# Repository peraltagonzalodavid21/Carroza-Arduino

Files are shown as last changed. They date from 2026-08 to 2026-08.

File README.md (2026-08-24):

## Bienvenida:
Buenasss, no se quien este leyendo esto, pero mientras voy comentando como esta planteado esto, en este repositorio se encuentra todo el codigo de la carroza, un poco de los diagramas para usar de referencia, ademas de intrucciones para poner a punto la placa y algunos consejos que pueden ser utiles al momento de armarla. Ademas del MIT app inventor para programar la app. Tambien voy a dejar las capturas y el archivo de kicad para futuras mejoras que voy a comentar al final.

## Creditos:

Aca aunque ya me conozcan dejo mi nombre y promo por si este repo se sigue utilizando:

Alumno: Peralta Gonzalo David
Promo: 2025
Colegio: E.P.E.T N°12
Año: 2026

## Hardware del Proyecto

El sistema de control funciona con los siguientes componentes:
* Microcontrolador: Arduino Nano (se utilizan todos los pines digitales del D2 al D13, 12 salidas en total).
* Módulo Bluetooth: HC-05 (para la conexión con la aplicación).
* Drivers de Potencia: ULN2003 para el manejo seguro de los relés.
* Actuadores: 12 Relés de 5V (4 para movimiento, 8 para accesorios/luces).
* Alimentación: Módulo Step-down LM2596 (Regula de 12V a 5V para alimentar la lógica).

## Diagrama de Pines (Pinout) y Mapeo Bluetooth

Es fundamental conectar los pines correctamente según la siguiente tabla:

| Relé / Función | Pin en Arduino | Tipo de Botón en App | Letra ON | Letra OFF |
|---|---|---|---|---|
| Relé 1 (Adelante) | D2 | Momentáneo | A | a |
| Relé 2 (Atrás) | D3 | Momentáneo | B | b |
| Relé 3 (Izquierda)| D4 | Momentáneo | C | c |
| Relé 4 (Derecha) | D5 | Momentáneo | D | d |
| Relé 5 (Mas)| D6 | Momentáneo | E | e |
| Relé 6 (Menos)| D7 | Momentáneo | F | f |
| Relé 7 (Accesorio 1)| D8 | Toggle (Interruptor) | G | g |
| Relé 8 (Accesorio 2)| D9 | Toggle (Interruptor) | H | h |
| Relé 9 (Accesorio 3)| D10 | Toggle (Interruptor) | I | i |
| Relé 10 (Accesorio 4)| D11 | Toggle (Interruptor) | J | j |
| Relé 11 (Accesorio 5)| D12 | Toggle (Interruptor) | K | k |
| Relé 12 (Accesorio 6)| D13 | Toggle (Interruptor) | L | l |
| EMERGENCIA (STOP) | N/A | Botón de Pánico | X | N/A |

Nota sobre el funcionamiento de los botones:
- Momentáneo: La acción se ejecuta solo mientras se mantiene presionado el botón en la aplicación.
- Toggle: Funciona como un interruptor estándar. Se presiona una vez para encender y otra para apagar.

## Guía de Instalación (5 Pasos)

Para poner en marcha el control de la carroza, seguir estos pasos:

1. Paso 1 - Cargar el código:
   Descargar el código Arduino desde este repositorio, abrirlo en el IDE y cargarlo al Arduino Nano (asegurarse de configurar el puerto y el tipo de placa correctos).
2. Paso 2 - Conectar los módulos:
   Conectar el módulo HC-05 (TX a RX y RX a TX del Arduino), el regulador LM2596 (ajustado a 5V) y el ULN2003 a los pines de los relés según la tabla anterior.
3. Paso 3 - Descargar la app:
   Descargar la aplicación desde el repositorio (archivo .aia) o importarla desde el enlace compartido de MIT App Inventor.
4. Paso 4 - Instalar y vincular:
   Instalar la aplicación en el dispositivo Android y vincular el módulo HC-05 mediante Bluetooth desde los ajustes del sistema.
5. Paso 5 - Probar la seguridad:
   Abrir la aplicación, conectar el Bluetooth y probar inmediatamente el botón de STOP (EMERGENCIA) para verificar que todos los relés se apagan correctamente.

## Cómo agregar un nuevo relé en 1 minuto

Si en el futuro es necesario agregar más funcionalidades, el procedimiento es el siguiente:

1. Ir al código Arduino, copiar una función rele13_ON() y su correspondiente OFF, pegarla y cambiarle el número.
2. Agregar un nuevo else if en la sección del loop() para capturar la nueva letra (por ejemplo, 'M' y 'm').
3. Actualizar el array de pines al inicio del código, si corresponde.
4. En la aplicación (MIT App Inventor), copiar un interruptor (switch) existente, cambiarle el nombre y configurarlo para que envíe las nuevas letras ('M' y 'm').

## Carpetas del repo
/Codigo_Arduino → Archivo .ino con el programa principal.

/App_MIT_Inventor → Archivo .aia de la app, Si se abre el mit app inventor pueden modificar la app.

/PCB_KiCad → Archivos del esquemático y diseño de la PCB, Si se abre el KiCad pueden modificar la PCB.

/Docs → Imágenes, diagramas, fotos de la carroza, etc. Aca tambien ya dejo un par de capturas de la carroza.

## Galería

Se recomienda agregar fotos de la PCB, los circuitos, el chasis y la carroza terminada en la carpeta /Docs como registro visual del trabajo. (Creen una carpeta con el año y fotos de la carroza, placa, etc). 

## Cierre
Bueno aca ya dejo el cierre, no se quien lea esto pero espero que el proyecto siga avanzando y mejoren, como un esp32 con mas pines y bluetooth integrado, ya que es el proximo paso, o que la carroza no se mueva sola pero tenga un show de luces o algo mas elaborado, como un sistema que se prenda solo cuando tenga musica fuerte, no se, depende de la creatividad de cada uno. 

Mientras tanto los dejo tranquilos, yo voy a ver si la facu no me mata, saludos.

-Peralta Gonzalo David.

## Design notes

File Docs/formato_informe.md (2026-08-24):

# INFORME TÉCNICO – CONTROL DE CARROZA ESTUDIANTINA

**Versión:** [AÑO]  
**Autor:**  
**Institución:** E.P.E.T N°12
**Fecha de emisión:** [Fecha de entrega del informe]  

---

## 1. OBJETIVO DEL PROYECTO

Desarrollar un sistema de control inalámbrico para la carroza de la Semana de la Estudiantina, que permita manejar los motores de desplazamiento y los accesorios (luces, bocinas, etc.) desde un dispositivo Android, reemplazando los engorrosos sistemas de cableado tradicionales y brindando seguridad y facilidad de operación a los estudiantes.

---

## 2. DESCRIPCIÓN DEL SISTEMA

### 2.1. Hardware utilizado
- **Microcontrolador:** Arduino Nano (ATmega328P).
- **Módulo Bluetooth:** HC-05 (esclavo).
- **Driver de relés:** [Especificar según año, ej: Transistores + optoacopladores / ULN2003].
- **Relés:** [Especificar voltaje y cantidad, ej: 12 relés de 12V].
- **Fuente de alimentación:** [Especificar, ej: LM2596 step-down (12V a 5V)].
- **PCB:** [Especificar, ej: Placa perforada / PCB personalizada con planchado].

### 2.2. Software utilizado
- **IDE de programación:** Arduino IDE (versión [indicar]).
- **Entorno de desarrollo de la app:** MIT App Inventor 2.
- **Diseño de PCB:** KiCad (versión [indicar]).
- **Lenguajes:** C++ (Arduino) / Bloques visuales (MIT App Inventor).

---

## 3. CRONOGRAMA Y HITOS

| Fecha | Hito / Actividad |
| :--- | :--- |
| [DD/MM] | [Descripción de la actividad, ej: Inicio del desarrollo del código] |
| [DD/MM] | [Descripción, ej: Primeras pruebas en protoboard] |
| [DD/MM] | [Descripción, ej: Fabricación de la PCB] |
| [DD/MM] | [Descripción, ej: Armado final y pruebas en carroza] |

*(Completar con las fechas reales del año correspondiente)*

---

## 4. MEJORAS Y CAMBIOS RESPECTO AL AÑO ANTERIOR

*(Si es la primera versión, aclarar que es el prototipo inicial)*

- [Mejora 1, ej: Se eliminaron los optoacopladores y se utilizó un ULN2003 para simplificar el circuito].
- [Mejora 2, ej: Se diseñó una PCB con método de planchado, reemplazando la placa perforada].
- [Mejora 3, ej: Se añadieron borneras para facilitar el cableado en la carroza].

---

## 5. INCIDENCIAS Y SOLUCIONES APLICADAS

| Problema encontrado | Solución implementada |
| :--- | :--- |
| [Ej: Se quemó un ULN2003 por inversión de polaridad] | [Ej: Se reemplazó el integrado y se agregó un diodo de protección en el esquemático] |
| [Ej: Contacto de bornera flojo en la carroza] | [Ej: Se ajustaron los tornillos y se verificó el apriete de todas las conexiones] |

---

## 6. CONCLUSIONES Y SUGERENCIAS PARA PRÓXIMAS VERSIONES

- **Conclusión general:** El sistema funcionó correctamente durante el evento, cumpliendo con los requisitos de manejo y seguridad.
- **Sugerencia 1:** Agregar un botón físico de emergencia en el tablero (independiente de la app).
- **Sugerencia 2:** Considerar reemplazar el HC-05 por un módulo BLE (HM-10) para compatibilidad con iOS.
- **Sugerencia 3:** Diseñar una carcasa protectora (impresión 3D) para la PCB.
- **Sugerencia 4:** Ampliar el número de relés si se agregan más accesorios (actualmente 12, se puede extender usando un multiplexor o cambiando de microcontrolador).

---

## 7. ANEXOS

- Código fuente (Arduino): disponible en `/Codigo_Arduino` del repositorio.
- App (MIT App Inventor): disponible en `/App_MIT_Inventor` y enlace de proyecto compartido.
- Esquemático y PCB (KiCad): disponibles en `/PCB_KiCad`.
- Fotos y diagramas: disponibles en `/Docs/imagenes`.

---

**Nota:** Este informe es un registro histórico del proyecto. Está sujeto a modificaciones y actualizaciones según los requerimientos de cada año, los avances tecnológicos y las lecciones aprendidas durante la puesta en marcha.

---
*“La técnica es el puente entre la idea y la realidad.”*

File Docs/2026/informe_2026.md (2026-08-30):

# INFORME TÉCNICO – CONTROL DE CARROZA ESTUDIANTINA

**Versión:** [2026]  
**Autor:** Adriel Nicolás Balbuena 
**Institución:** E.P.E.T N°12
**Fecha de emisión:** [24/08/26]  

---

## 1. OBJETIVO DEL PROYECTO

Desarrollar un sistema de control inalámbrico para la carroza de la Semana de la Estudiantina, que permita manejar los motores de desplazamiento y los accesorios (luces, bocinas, etc.) desde un dispositivo Android, reemplazando los engorrosos sistemas de cableado tradicionales y brindando seguridad y facilidad de operación a los estudiantes.

---

## 2. DESCRIPCIÓN DEL SISTEMA

### 2.1. Hardware utilizado
- **Microcontrolador:** Arduino Nano (ATmega328P).
- **Módulo Bluetooth:** HC-05 (esclavo).
- **Driver de relés:** [Especificar según año, ej: Transistores + optoacopladores / ULN2003].
- **Relés:** [Especificar voltaje y cantidad, ej: 12 relés de 12V].
- **Fuente de alimentación:** [Especificar, ej: LM2596 step-down (12V a 5V)].
- **PCB:** [Especificar, ej: Placa perforada / PCB personalizada con planchado].

### 2.2. Software utilizado
- **IDE de programación:** Arduino IDE (versión [indicar]).
- **Entorno de desarrollo de la app:** MIT App Inventor 2.
- **Diseño de PCB:** KiCad (versión [indicar]).
- **Lenguajes:** C++ (Arduino) / Bloques visuales (MIT App Inventor).

---

## 3. CRONOGRAMA E HITOS

| Fecha | Hito / Actividad |
| :--- | :--- |
| [DD/MM] | [Descripción de la actividad, ej: Inicio del desarrollo del código] |
| [DD/MM] | [Descripción, ej: Primeras pruebas en protoboard] |
| [DD/MM] | [Descripción, ej: Fabricación de la PCB] |
| [DD/MM] | [Descripción, ej: Armado final y pruebas en carroza] |
| 26/08 | Desoldado del HC-05 para pruebas con el Arduino Nano. |
| 26/08 | Preparación de planchas para la colocación de los finales de carrera. |
| 28/08 | Colocación de los finales de carrera. |
*(Completar con las fechas reales del año correspondiente)*

---

## 4. MEJORAS Y CAMBIOS RESPECTO AL AÑO ANTERIOR

*(Si es la primera versión, aclarar que es el prototipo inicial)*

- [Mejora 1, ej: Se eliminaron los optoacopladores y se utilizó un ULN2003 para simplificar el circuito].
- [Mejora 2, ej: Se diseñó una PCB con método de planchado, reemplazando la placa perforada].
- [Mejora 3, ej: Se añadieron borneras para facilitar el cableado en la carroza].

---

## 5. INCIDENCIAS Y SOLUCIONES APLICADAS

| Problema encontrado | Solución implementada |
| :--- | :--- |
| [Ej: Se quemó un ULN2003 por inversión de polaridad] | [Ej: Se reemplazó el integrado y se agregó un diodo de protección en el esquemático] |
| [Ej: Contacto de bornera flojo en la carroza] | [Ej: Se ajustaron los tornillos y se verificó el apriete de todas las conexiones] |

---

## 6. CONCLUSIONES Y SUGERENCIAS PARA PRÓXIMAS VERSIONES

- **Conclusión general:** El sistema funcionó correctamente durante el evento, cumpliendo con los requisitos de manejo y seguridad.
- **Sugerencia 1:** Agregar un botón físico de emergencia en el tablero (independiente de la app).
- **Sugerencia 2:** Considerar reemplazar el HC-05 por un módulo BLE (HM-10) para compatibilidad con iOS.
- **Sugerencia 3:** Diseñar una carcasa protectora (impresión 3D) para la PCB.
- **Sugerencia 4:** Ampliar el número de relés si se agregan más accesorios (actualmente 12, se puede extender usando un multiplexor o cambiando de microcontrolador).

---

## 7. ANEXOS

- Código fuente (Arduino): disponible en `/Codigo_Arduino` del repositorio.
- App (MIT App Inventor): disponible en `/App_MIT_Inventor` y enlace de proyecto compartido.
- Esquemático y PCB (KiCad): disponibles en `/PCB_KiCad`.
- Fotos y diagramas: disponibles en `/Docs/imagenes`.

---

**Nota:** Este informe es un registro histórico del proyecto. Está sujeto a modificaciones y actualizaciones según los requerimientos de cada año, los avances tecnológicos y las lecciones aprendidas durante la puesta en marcha.

---
*“La técnica es el puente entre la idea y la realidad.”*

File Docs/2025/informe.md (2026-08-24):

# Informe del Proyecto – Control de Carroza Estudiantina

**Autor:** Peralta Gonzalo David (Promo 2025)  
**Última actualización:** Agosto 2026  
**Estado:** Funcional / En mantenimiento

---

## 1. Resumen del proyecto

Sistema de control inalámbrico para la carroza de la Semana de la Estudiantina, basado en Arduino Nano y Bluetooth (HC-05). Permite activar 12 relés (4 para motores de desplazamiento y 8 para accesorios) desde una app Android desarrollada en MIT App Inventor. El proyecto fue evolucionando desde prototipos en placa perforada hasta una PCB personalizada con planchado.

---

## 2. Línea de tiempo y versiones

### Versión 2024 (Prototipo inicial)

| Fecha | Hito |
| :--- | :--- |
| Mayo 2024 | Inicio del desarrollo – primer prototipo funcional en protoboard. |
| Julio 2024 | Montaje en placa perforada con relés de 5V, optoacopladores y transistores. |
| Septiembre 2024 | Pruebas en carroza con control básico (4 movimientos + luces). |
| Octubre 2024 | Presentación en la estudiantina (funcionó correctamente). |

**Hardware utilizado:**
- Arduino Nano
- HC-05
- Relés de 5V (con optoacopladores y transistores para manejo)
- PCB perforada (no diseñada, todo cableado manual)

**Aprendizajes y limitaciones:**
- Cableado manual difícil de mantener.
- Los optoacopladores agregaban complejidad innecesaria.
- No se realizó un diseño de PCB.

---

### Versión 2025 (PCB planchada y optimización)

| Fecha | Hito |
| :--- | :--- |
| 22 de mayo | Inicio del desarrollo de la app en MIT App Inventor. |
| 23 de junio | Pruebas funcionales completas en protoboard (código listo). |
| 5 de septiembre | PCB terminada con método de planchado (diseño en KiCad). |
| 8 de septiembre | Armado del tablero de control y cableado provisional. |
| 15 de septiembre | Instalación final en la carroza y pruebas de campo. |

**Mejoras implementadas respecto a 2024:**
- PCB personalizada (método de planchado) – reemplazo de placa perforada.
- Uso de ULN2003 (arrays de Darlingtons) para manejar relés de 12V, eliminando optoacopladores y transistores discretos.
- Alimentación estabilizada con LM2596 (step‑down de 12V a 5V).
- Borneras para facilitar conexiones.
- Esquemático eléctrico en KiCad.
- Se ocuparon todos los pines digitales (D2‑D13) para los 12 relés.

**¿Qué se rompió o falló?**
- Durante la instalación, se quemó un ULN2003 por inversión de polaridad en la alimentación (se reemplazó y se agregó un diodo de protección en el esquemático para futuras revisiones).

---

## 3. Estado actual del proyecto (2026)

- El código y la app funcionan correctamente.
- La PCB está en uso y no presenta fallas.
- El repositorio contiene:
  - Código Arduino (`.ino`).
  - App MIT App Inventor (`.aia`).
  - Archivos de KiCad (esquemático y PCB).
  - Fotos del armado y la carroza.

---

## 4. Sugerencias para futuras versiones

1. **Agregar un relé extra** (13 o más) ampliando el array de pines y las funciones en el código. Es tan sencillo como copiar/pegar una función existente.
2. **Implementar secuencias automáticas** (ej. luces intermitentes o coreografías) usando `millis()` sin bloquear el Bluetooth. Ya hay espacio en la app para agregar botones de "modo automático".
3. **Diseñar una carcasa 3D** para el tablero de control que proteja la PCB de la intemperie.
4. **Reemplazar el HC-05 por un módulo BLE** (como HM‑10) si se quiere compatibilidad con iPhones (el HC‑05 solo funciona bien en Android).
5. **Añadir un botón físico de emergencia** en el tablero (aparte del botón en la app) por si el celular se queda sin batería.

---

## 5. Agradecimientos y contacto

No se si posta van a leer todo esto por su bien espero que si, asi que nada mucha suerte con todo, un saludo al profe buja y el profe sanabria.

**Autor:** Peralta Gonzalo David – Técnico Electromecánico (Promo 2025).

---

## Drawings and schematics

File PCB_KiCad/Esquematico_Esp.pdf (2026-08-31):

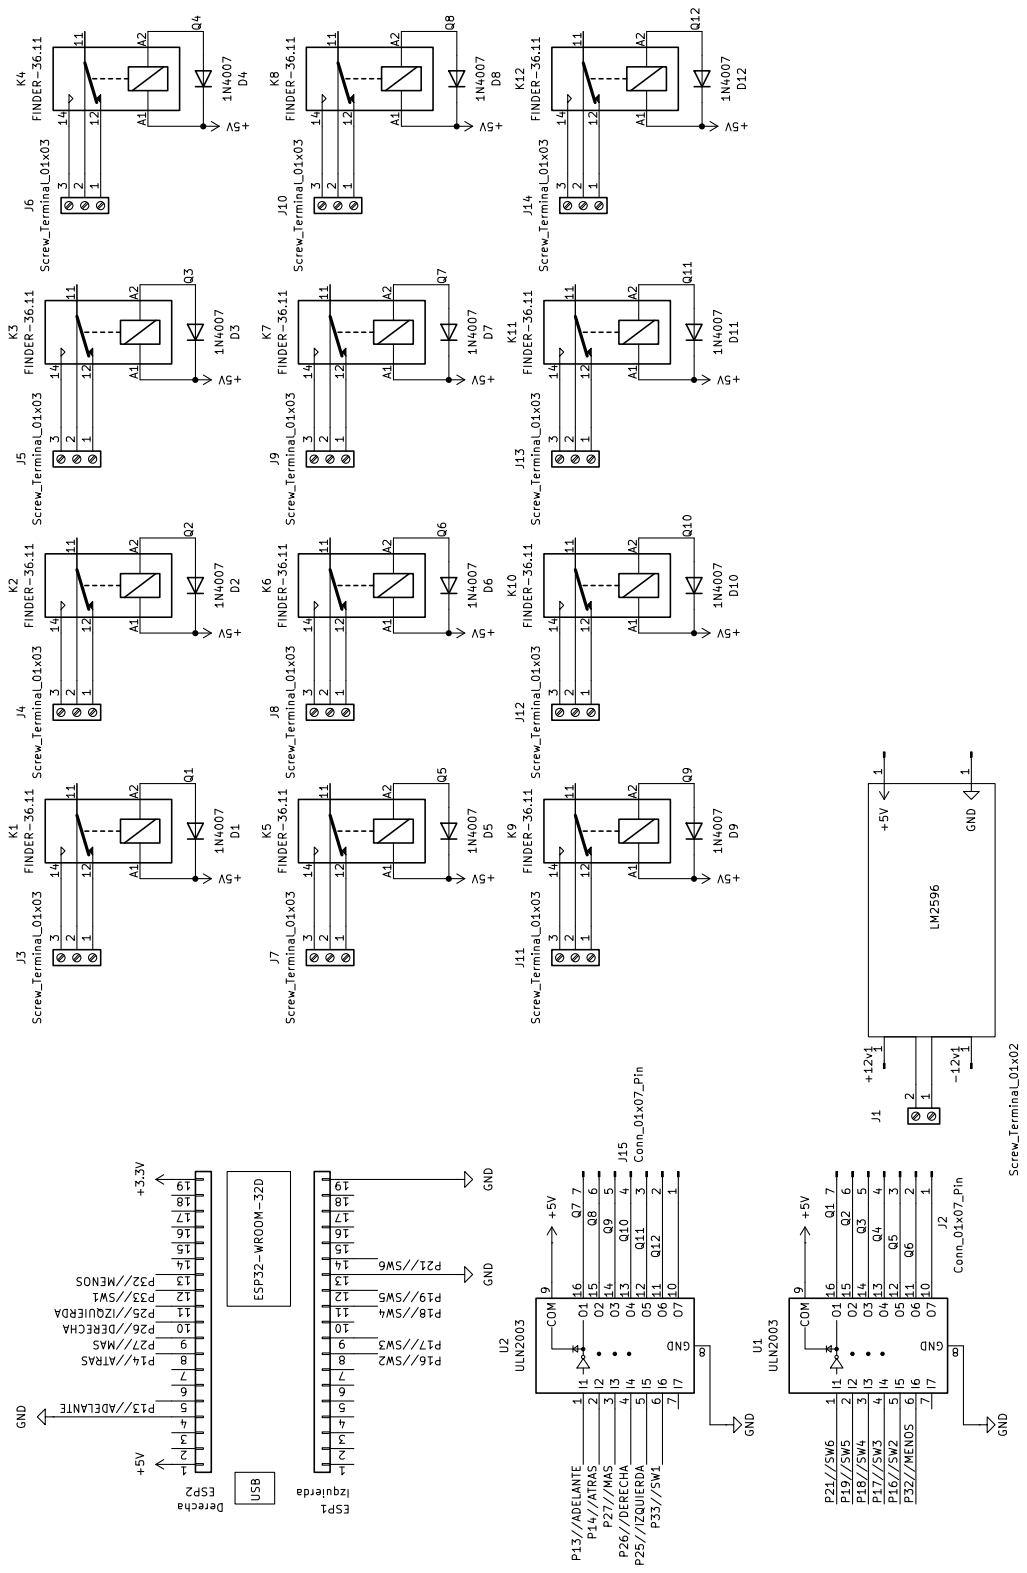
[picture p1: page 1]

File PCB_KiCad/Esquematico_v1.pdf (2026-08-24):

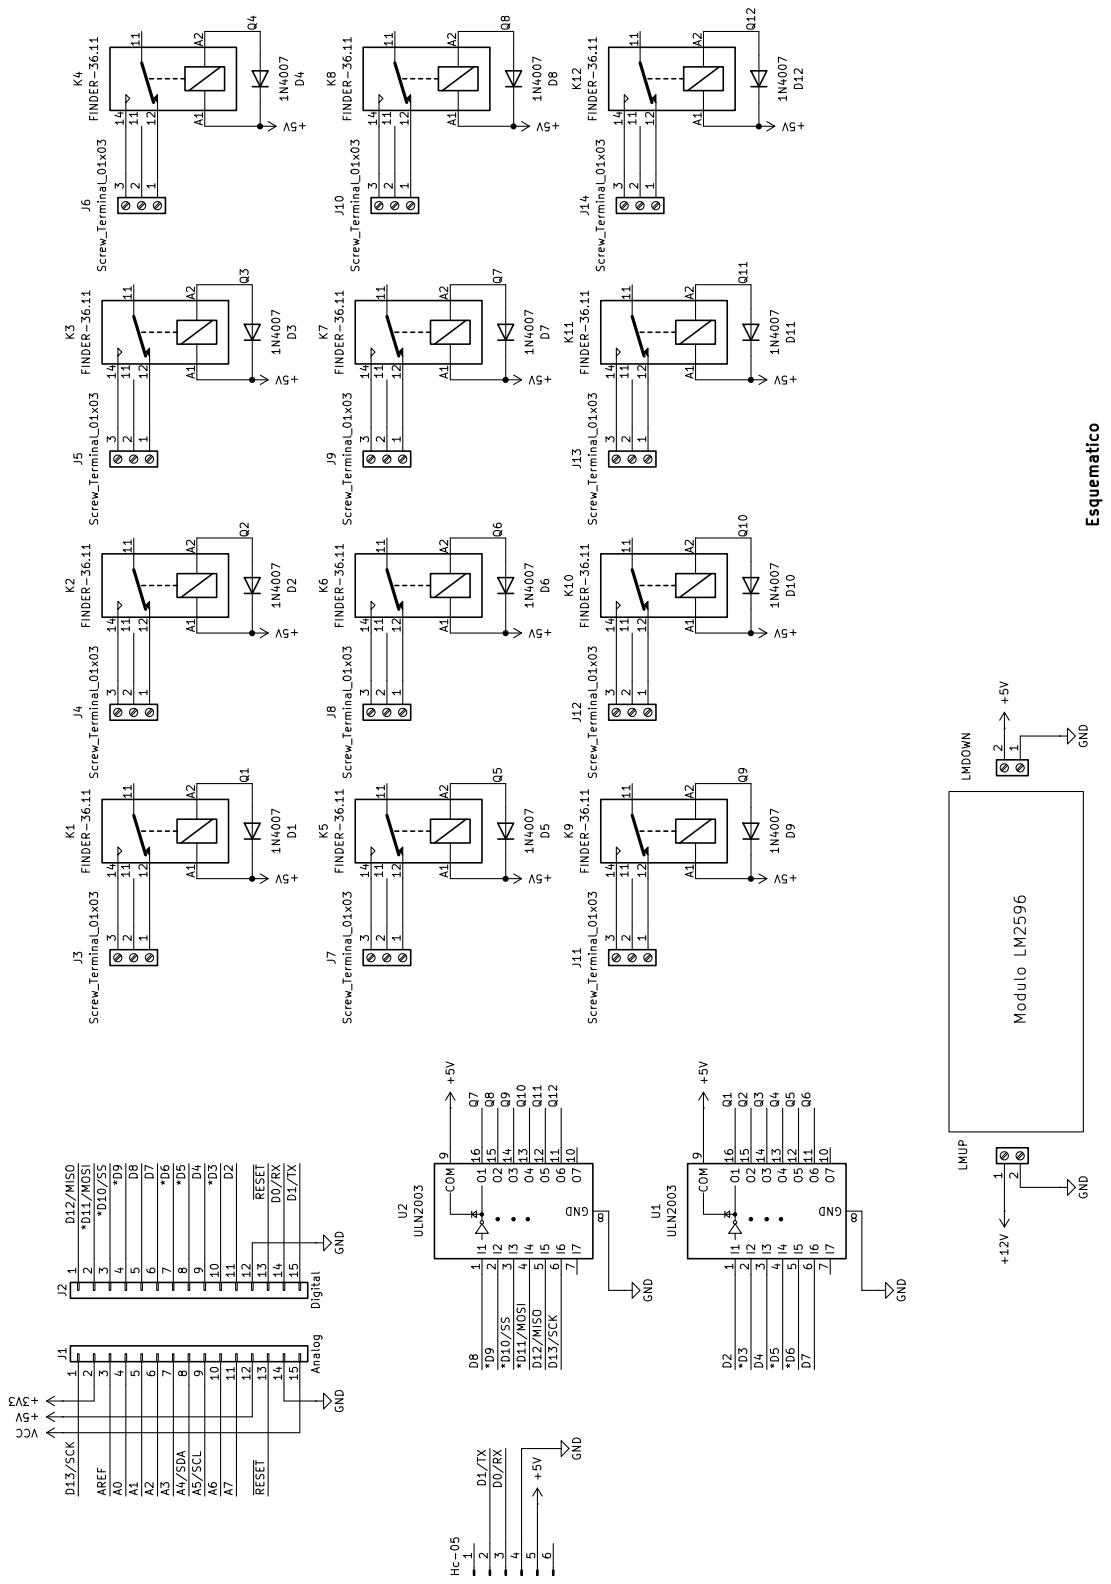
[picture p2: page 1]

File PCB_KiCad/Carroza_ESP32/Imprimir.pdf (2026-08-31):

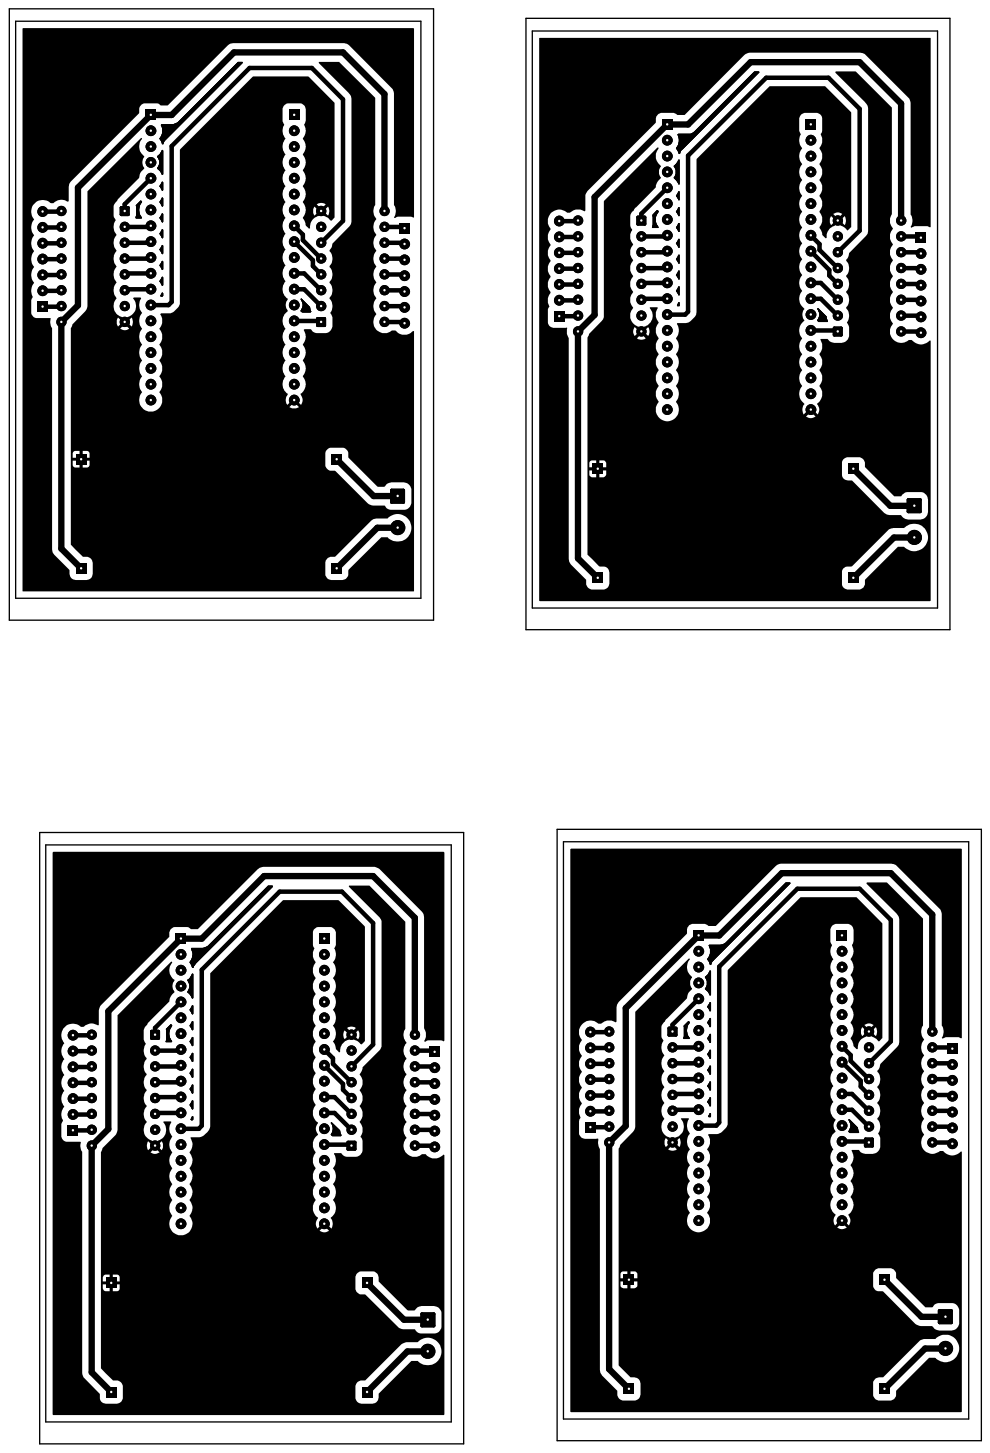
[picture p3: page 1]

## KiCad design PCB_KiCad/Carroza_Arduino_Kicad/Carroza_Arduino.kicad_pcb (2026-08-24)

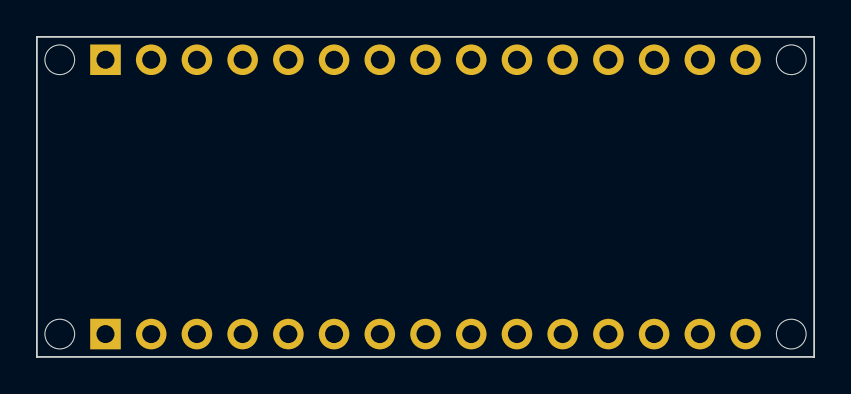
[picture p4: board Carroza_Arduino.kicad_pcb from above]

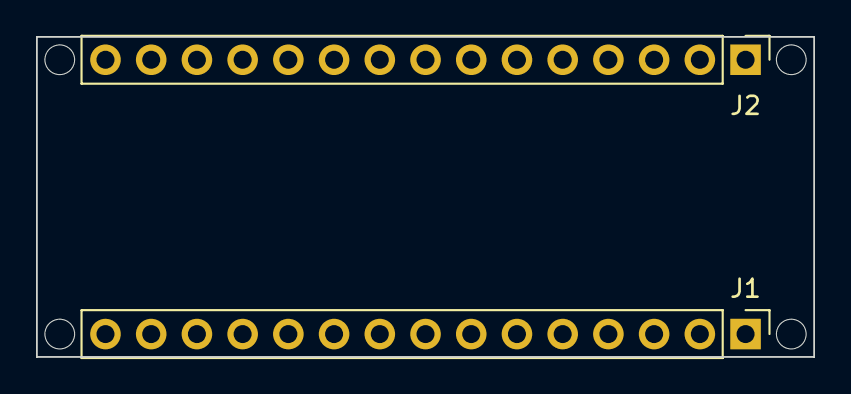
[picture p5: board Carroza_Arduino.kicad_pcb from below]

Board: 2 copper layers, 43.2 x 17.8 mm, 6 parts (2 on the bottom side), 2 nets, no tracks yet.

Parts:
J1: Analog; PinHeader_1x15_P2.54mm_Vertical
J2: Digital; PinHeader_1x15_P2.54mm_Vertical
MH1, MH2, MH3, MH4: MountingHole_65mil

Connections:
/~RESET: J1.13, J2.13
GND: J1.14, J2.12

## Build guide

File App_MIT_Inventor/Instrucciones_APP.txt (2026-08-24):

INSTRUCCIONES PARA MODIFICAR LA APP EN MIT APP INVENTOR
=======================================================
Hola chicos. Aquí David. 
Sigan estos pasos al pie de la letra para que la app no explote. 
(Tranquilos, es a prueba de errores si saben leer y copiar).

1. PREPARACIÓN INICIAL
   - Entren a MIT App Inventor y abran el proyecto (.aia).
   - Vayan a la vista de "Blocks" (arriba a la derecha).

2. BOTONES DE MOVIMIENTO (Adelante, Atrás, Izquierda, Derecha) - MODO MOMENTÁNEO
   Queremos que la carroza se mueva SOLO mientras mantienes el dedo en la pantalla.
   
   - Para el botón "Adelante" (Relé 1):
     a) Busquen el bloque amarillo: `when Boton_Adelante.TouchDown do`
     b) Adentro, pongan el bloque morado para enviar texto por Bluetooth: 
        `call BluetoothClient1.SendText text "A"` (¡LA 'A' MAYÚSCULA ENCIENDE!)
     c) Ahora busquen el bloque amarillo: `when Boton_Adelante.TouchUp do`
     d) Adentro, pongan: 
        `call BluetoothClient1.SendText text "a"` (¡LA 'a' MINÚSCULA APAGA!)

   - Repitan esto para los otros 3 botones:
     Boton_Atras -> TouchDown envia "B" / TouchUp envia "b"
     Boton_Izquierda -> TouchDown envia "C" / TouchUp envia "c"
     Boton_Derecha -> TouchDown envia "D" / TouchUp envia "d"

3. BOTONES DE ACCESORIOS Y LUCES (Relé 5 al 12) - MODO TOGGLE
   Queremos que presiones una vez y se prenda, y presiones de nuevo y se apague.
   
   - Vamos a necesitar VARIABLES para recordar si está prendido o apagado.
   - Para el Relé 5:
     a) Creen una variable global (naranja): `initialize global estado_rele5 to false`
     b) Busquen el bloque del botón: `when Boton_Rele5.Click do`
     c) Adentro pongan un bloque de control (if/then/else):
        if `get global estado_rele5` == false then:
            `call BluetoothClient1.SendText text "E"`
            `set global estado_rele5 to true`
        else:
            `call BluetoothClient1.SendText text "e"`
            `set global estado_rele5 to false`

   - Repitan esta lógica exacta para los botones 6 al 12, usando su letra correspondiente:
     Relé 6 -> Click usa "F" y "f", variable estado_rele6
     Relé 7 -> Click usa "G" y "g", variable estado_rele7
     Relé 8 -> Click usa "H" y "h", variable estado_rele8
     Relé 9 -> Click usa "I" y "i", variable estado_rele9
     Relé 10 -> Click usa "J" y "j", variable estado_rele10
     Relé 11 -> Click usa "K" y "k", variable estado_rele11
     Relé 12 -> Click usa "L" y "l", variable estado_rele12

4. BOTÓN DE EMERGENCIA (¡EL BOTÓN DEL PÁNICO!)
   Este botón apaga todo de un solo golpe (manda la señal X que apaga todos los relés).
   
   - Busquen el bloque: `when Boton_Emergencia.Click do`
   - Adentro pongan: `call BluetoothClient1.SendText text "X"`
   - (Opcional, pero muy recomendado): Si apretaron emergencia, también pongan todas las variables globales de estado (estado_rele5 hasta estado_rele12) en `false`, así la app recuerda que todo se acaba de apagar en caso de que quieran volver a prender algo.

¡Y LISTO! Compilen la app (.apk), pásenla al celular y a probarla. ¡No rompan la carroza!

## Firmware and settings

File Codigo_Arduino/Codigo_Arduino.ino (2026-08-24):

// PROYECTO: Control de Carroza - Semana de la Estudiantina
// AUTOR: David 
// HARDWARE: Arduino Nano, HC-05 (Bluetooth), ULN2003, Módulo de 12 Relés

// Array con los pines digitales usados para los 12 relés (D2 a D13)
// IMPORTANTE: El índice del array empieza en 0.
// pinesRelevadores[0] corresponde al Relé 1 (Pin 2).
int pinesRelevadores[] = {2, 3, 4, 5, 6, 7, 8, 9, 10, 11, 12, 13};

void setup() {
  // Iniciamos la comunicación serial para el Bluetooth a 9600 baudios
  Serial.begin(9600);

  // Configuramos todos los pines de los relés como SALIDA y los apagamos
  for (int i = 0; i < 12; i++) {
    pinMode(pinesRelevadores[i], OUTPUT);

    // Suponiendo lógica inversa para los módulos de relés comunes (HIGH =
    // apagado). Cambiar a LOW si el módulo de relés usa lógica directa.
    digitalWrite(pinesRelevadores[i], HIGH);
  }
}

void loop() {
  // Comprobamos si nos llega algún comando desde la App (Bluetooth)
  if (Serial.available() > 0) {
    char comando = Serial.read();

    // =============== MOVIMIENTO (Botones Momentáneos) ===============
    // Adelante
    if (comando == 'A') {
      rele1_ON();
    } else if (comando == 'a') {
      rele1_OFF();
    }
    // Atrás
    else if (comando == 'B') {
      rele2_ON();
    } else if (comando == 'b') {
      rele2_OFF();
    }
    // Izquierda
    else if (comando == 'C') {
      rele3_ON();
    } else if (comando == 'c') {
      rele3_OFF();
    }
    // Derecha
    else if (comando == 'D') {
      rele4_ON();
    } else if (comando == 'd') {
      rele4_OFF();
    }

    // =============== ACCESORIOS / LUCES (Botones Toggle) ===============
    // Mas
    else if (comando == 'E') {
      rele5_ON();
    } else if (comando == 'e') {
      rele5_OFF();
    }
    // Menos
    else if (comando == 'F') {
      rele6_ON();
    } else if (comando == 'f') {
      rele6_OFF();
    }
    // SW1
    else if (comando == 'G') {
      rele7_ON();
    } else if (comando == 'g') {
      rele7_OFF();
    }
    // SW2
    else if (comando == 'H') {
      rele8_ON();
    } else if (comando == 'h') {
      rele8_OFF();
    }
    // SW3
    else if (comando == 'I') {
      rele9_ON();
    } else if (comando == 'i') {
      rele9_OFF();
    }
    // SW4
    else if (comando == 'J') {
      rele10_ON();
    } else if (comando == 'j') {
      rele10_OFF();
    }
    // SW5
    else if (comando == 'K') {
      rele11_ON();
    } else if (comando == 'k') {
      rele11_OFF();
    }
    // SW6
    else if (comando == 'L') {
      rele12_ON();
    } else if (comando == 'l') {
      rele12_OFF();
    }

    // =============== EMERGENCIA ===============
    else if (comando == 'X') {
      apagarTodo();
    }
  }
}

// ==============================================================================
// FUNCIÓN BASE: Controla un relé específico
// id: Número del relé (1 a 12)
// estado: true (ON), false (OFF)
// ==============================================================================
void controlarRele(int id, bool estado) {
  int indice = id - 1; // Ajustamos al índice del array (Relé 1 -> Índice 0)
  if (indice >= 0 && indice < 12) {
    // Si el módulo de relés se activa con LOW, usamos lógica inversa (estado ?
    // LOW : HIGH) Si se activa con HIGH, cambia esto a:
    // digitalWrite(pinesRelevadores[indice], estado ? HIGH : LOW);
    digitalWrite(pinesRelevadores[indice], estado ? LOW : HIGH);
  }
}

// Función de EMERGENCIA: ¡Apaga todo de un solo golpe!
void apagarTodo() {
  for (int i = 1; i <= 12; i++) {
    controlarRele(i, false);
  }
  Serial.println("EMERGENCIA: Todo apagado");
}

// ==============================================================================
// FUNCIONES INDIVIDUALES (Para que los pibes solo copien y peguen)
// ==============================================================================

void rele1_ON() { controlarRele(1, true); }
void rele1_OFF() { controlarRele(1, false); }

void rele2_ON() { controlarRele(2, true); }
void rele2_OFF() { controlarRele(2, false); }

void rele3_ON() { controlarRele(3, true); }
void rele3_OFF() { controlarRele(3, false); }

void rele4_ON() { controlarRele(4, true); }
void rele4_OFF() { controlarRele(4, false); }

void rele5_ON() { controlarRele(5, true); }
void rele5_OFF() { controlarRele(5, false); }

void rele6_ON() { controlarRele(6, true); }
void rele6_OFF() { controlarRele(6, false); }

void rele7_ON() { controlarRele(7, true); }
void rele7_OFF() { controlarRele(7, false); }

void rele8_ON() { controlarRele(8, true); }
void rele8_OFF() { controlarRele(8, false); }

void rele9_ON() { controlarRele(9, true); }
void rele9_OFF() { controlarRele(9, false); }

void rele10_ON() { controlarRele(10, true); }
void rele10_OFF() { controlarRele(10, false); }

void rele11_ON() { controlarRele(11, true); }
void rele11_OFF() { controlarRele(11, false); }

void rele12_ON() { controlarRele(12, true); }
void rele12_OFF() { controlarRele(12, false); }

// ==============================================================================
// SI QUIERES AGREGAR EL RELÉ 13, COPIA UNA FUNCIÓN DE ARRIBA,
// PÉGALA AQUÍ ABAJO Y CAMBIA EL NÚMERO (Ejemplo: rele13_ON, controlarRele(13,
// true)). ¡No te olvides de agregar el nuevo pin en el array 'pinesRelevadores'
// al principio y su correspondiente 'else if' en el loop()!
// ==============================================================================

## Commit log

2026-08-24 Actualizacion del Readme y ajuste en el codigo
2026-08-24 ultimo comit david
    [Carroza_Arduino.kicad_pcb, Carroza_Arduino.kicad_sch]
2026-08-24 Codigo esp32
    un codigo para pruebas en el esp32
2026-08-24 devuelta codigo esp32
2026-08-30 PCB Esp32
    [Carroza_ESP32.kicad_pcb, Carroza_ESP32.kicad_sch]
